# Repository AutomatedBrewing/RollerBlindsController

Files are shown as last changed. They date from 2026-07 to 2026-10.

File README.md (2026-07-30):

# Embedded build system
Sample implementation

## Setup

Before building, install all required dependencies:

```bash
./setup_repo.sh
```

For detailed information about dependencies, see [DEPENDENCIES.md](DEPENDENCIES.md).

## Building
To build specific target:
`./build.sh -c blink_F072`

## Formatting & Linting

The project uses `clang-format` and `clang-tidy` for code quality.

You can:
1. Format whole codebase: `./format_all.sh`
2. Run linting: `./lint_all.sh`
3. Check formatting on commit: `git-clang-format --diff --style=file HEAD`

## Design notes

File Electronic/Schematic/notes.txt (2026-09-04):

Simulate input
Add debug probes
Chose pin headers

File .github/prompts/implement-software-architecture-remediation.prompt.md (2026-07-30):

---
description: "Implements Project/Model/Architecture/software/REMEDIATION_PLAN.md phase by phase with maximum rigor: edits .sysml model files, self-verifies every change against SysML v2 rules and existing conventions, then runs a final adversarial re-review until zero Critical/Major findings remain. Read-write — the counterpart to review-software-architecture.prompt.md."
---

# Implement Software Architecture Remediation

Act as an extremely meticulous senior firmware/systems architect. This
prompt **modifies `.sysml` files**. Quality bar: every change must be
correct, minimal, consistent with existing model conventions, and never
based on invented facts. When a plan item is ambiguous or requires a
decision the model doesn't already support, **stop and ask the user**
instead of guessing.

## Step 0 — Load context (mandatory, in order)

1. `Project/Model/Architecture/software/REVIEW_FINDINGS.md` and
   `REMEDIATION_PLAN.md` — the exact scope of this work.
2. `.github/instructions/sysml-modeling.instructions.md` — binding rules for
   every edit (imports, requirement pattern, decomposition levels, proxy
   ports, `perform action`, anti-patterns).
3. Every file already under `Architecture/software/` (all subfolders) plus
   `Architecture/product/ProductComponents.sysml`, `ProductInterfaces.sysml`,
   `Architecture/states/SystemStates.sysml`, `Architecture/base/ADR_Common.sysml`,
   `Traceability/Traceability.sysml`.
4. `KnowledgeSource/swarch/crossmapping/building-block-view.md`,
   `cross-cutting-concepts.md`, `architecture-decisions.md` — the modeling
   patterns each new element must follow.
5. `KnowledgeSource/integration/okf-ontology.md §6.3` — required import
   matrix.

## Step 1 — Execute phases in order

Follow `REMEDIATION_PLAN.md` exactly, phase by phase (Phase 4 may run
concurrently with 1–3 since it has no dependency on them; do not reorder
otherwise — later phases depend on earlier decisions):

- **Phase 1** — ADR-SW-011 software layering decision.
- **Phase 2** — Event catalog + `EventDispatcher` element.
- **Phase 3** — Driver layer + inventory (5 new drivers, 3 new `*Internal`
  whitebox specializations, `PLAN.md` scoping update).
- **Phase 4** — Hierarchical state machine fixes (composite `Operational`
  super-state, dedupe `PowerLost` transitions, resolve `MovingManual` gap,
  dual-host summary table).
- **Phase 5** — Traceability wiring (import every `SWA-0x` package into
  `Traceability.sysml`, add `refines`/`depends_on` connections).
- **Phase 6** — Documentation conciseness (split the ~100-line
  `SWSolutionStrategy` doc block, trim `SWBuildingBlocks` header).
- **Phase 7** — Housekeeping (`Project/Model/README.md` folder-tree entry,
  naming-convention decision).

## Step 2 — Non-negotiable quality rules for every edit

- Every new/edited `.sysml` file has explicit `import` statements per the
  matrix in `okf-ontology.md §6.3` — no unresolved-type errors.
- New whitebox modules are added via specialization (`part def X_Internal :>
  ExistingPartDef`) — never by re-declaring an existing definition's name
  (SysML v2 has no reopening mechanism).
- Drivers stay **signature-free**: name, responsibility, owning module,
  layer placement only. No method/API design — that is explicitly SDD scope
  and must stay out.
- No invented technical facts. Every timing figure, attribute value, or
  responsibility statement must already exist in the model or be a direct,
  citable consequence of an existing ADR/constraint. If a genuinely new
  fact is unavoidable (e.g., a driver's resource estimate), mark it as an
  explicit placeholder attribute with a `// TODO` doc note rather than
  fabricating a precise number.
- `doc` blocks are short and information-dense: state the fact, cite the
  ADR/requirement/finding ID that justifies it, stop. No multi-topic essay
  blocks (this was Finding SWR-026 — do not reintroduce it anywhere).
- Every finding ID resolved by an edit gets a one-line comment reference
  (e.g., `// resolves SWR-006`) at the point of the fix, so the connection
  between finding and fix is visible in the diff.
- Proxy ports only, `part def` for structural elements (never SysML v1
  `actor`/`block`), two-layer requirement pattern where requirements are
  touched.
- Preserve every existing element's name, port, and attribute unless the
  plan item explicitly calls for a change — additive, non-invasive edits
  only.

## Step 3 — Self-verification after each phase

Before moving to the next phase, re-read your own edits adversarially
against this checklist (same categories as the review prompt, scoped to
what you just changed):

- **Compiles conceptually**: every referenced type/port/action exists;
  no dangling reference.
- **Layering**: no Application-level module reaches past its driver into
  raw hardware ports.
- **Drivers**: each new driver has exactly one owning module, one clear
  responsibility, no overlap with another driver.
- **Events**: every event in the catalog has a producer and at least one
  consumer; no orphan or unproduced event.
- **State machine**: every state has ≥1 outgoing transition or is
  explicitly terminal; every transition has a named trigger (or is a
  documented completion transition); guards sharing a trigger stay
  mutually exclusive; no duplicated transition logic across sibling states
  after Phase 4.
- **Traceability**: every new package is imported somewhere it should be
  reachable from `Traceability.sysml` by Phase 5's end.
- **Conciseness**: no `doc` block you wrote exceeds ~5 lines of substantive
  text.

Fix anything that fails before proceeding.

## Step 4 — Final acceptance pass (mandatory, after Phase 7)

Re-run the full adversarial review from `review-software-architecture.prompt.md`
Steps 2 (categories A–G) across the entire `Architecture/software/` folder
plus `SystemStates.sysml` and `Traceability.sysml`, as if you had not just
made the changes yourself. For every one of the 28 original findings
(`SWR-001`…`SWR-028`):
- Confirm it is now closed, and how.
- Or, if intentionally deferred (e.g., SWR-027's retroactive ADR-001–010
  tightening), state that explicitly with a reason — never silently drop it.

Update `Project/Model/Architecture/software/REVIEW_FINDINGS.md` in place:
add a `Status` column (`Closed` / `Deferred` + reason) to the existing
table, and update the Summary counts.

Update `REMEDIATION_PLAN.md`'s final line to reflect the new state:
`<N> Critical / <N> Major / <N> Minor open — READY for SDD handoff` (only
write `READY` once zero Critical/Major remain), or list what's still open
and why.

If the re-review surfaces any **new** finding introduced by your own edits,
add it to the findings table with a fresh `SWR-0NN` ID, fix it immediately
(this phase is read-write), and re-verify.

## Step 5 — Summary to user

End with a short report: phases completed, files created/edited (list),
findings closed vs. deferred (counts), and the final verdict line from
Step 4. No long narrative — bullet points only.

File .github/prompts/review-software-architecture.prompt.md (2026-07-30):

---
description: "Pedantic, exhaustive review of the firmware software architecture (layering, drivers/HAL, event catalog & signal flow, hierarchical state machine) under Project/Model/Architecture/software. Logs every finding, then produces a prioritized remediation plan. Read-only — never edits any .sysml file."
---

# Review Software Architecture (Pedantic)

Act as an extremely pedantic senior firmware/systems architecture reviewer.
**Read-only review** — do not modify any `.sysml` file. The only files you
write are the two reports in Step 3 and Step 4.

## Why this review exists

The current software architecture model
(`Project/Model/Architecture/software/`) stops short on four points:
1. No explicit software **layering** (Application/Service vs. Driver/HAL vs.
   hardware).
2. No explicit inventory of low-level **drivers** that must be written
   (HAL only — driver API/method signatures are SDD-level, out of scope here).
3. No single, readable **event catalog** and signal flow — events are only
   mentioned in ADR prose, never enumerated as first-class elements.
4. No confirmed-complete **hierarchical state machine** — states/transitions
   must all be explicit, unambiguous, and traceable.

Every finding and every remediation item must be short and concrete —
engineers reading this have no time for long paragraphs.

## Step 1 — Load context (read only)

Read, in order:
1. `Project/Model/README.md`, `Architecture/software/PLAN.md`.
2. `Architecture/base/BaseArchitecture.sysml`, `ADR_001`…`ADR_008`, `Constraints.sysml`, `SystemArchitecture_Taxonomy.sysml`.
3. `Architecture/product/ProductComponents.sysml`, `ProductInterfaces.sysml`, `LogicalToProductAllocation.sysml`.
4. `Architecture/states/SystemStates.sysml`.
5. Everything under `Architecture/software/`: `architecture_decisions/ADR_009_*`, `ADR_010_*`; `architecture_constraints/SWConstraints.sysml`; `building_block_view/SWBuildingBlocks.sysml`; `runtime_view/SWRuntimeScenarios.sysml`; `deployment_view/SWResourceBudget.sysml`; `cross_cutting_concepts/SWCrossCuttingConcepts.sysml`; `solution_strategy/SWSolutionStrategy.sysml`.
6. `KnowledgeSource/integration/crossmapping/physical-architecture.md`, `logical-architecture.md`, `product-architecture.md`, `system-states.md`.
7. `.github/instructions/sysml-modeling.instructions.md`.

## Step 2 — Review checklist (log EVERY finding — do not silently skip)

For each finding record: `ID` (`SWR-NNN`), `Severity`, `Area`,
`File:Element`, one-line `Finding`, one-line `Impact`.

**Severity**: `Critical` = blocks SDD handoff / structurally wrong or
missing; `Major` = real gap that must close before implementation starts;
`Minor` = wording/consistency/style nit.

### A. Software Layering
- Is there an explicit layered architecture (Application/Service ↔
  Driver/HAL ↔ hardware) modeled as packages/`part def`s with a documented
  boundary? (Expect: not yet — flag.)
- Does any firmware module (`CommandArbitrationSoftware`,
  `MovementControlSoftware`, `MotorDriveControlSoftware`,
  `MovementSupervisorSoftware`, `ConfigurationManagerSoftware`,
  `MemoryManagerSoftware`, `UserFeedbackSoftware`) reference hardware
  directly instead of through a driver abstraction? Flag every skipped
  layer.

### B. Driver Inventory (HAL only — NOT the API/SDD layer)
- Cross-reference every hardware peripheral implied by `ControlMCU` /
  `ProductInterfaces` / the ADRs: 4× debounced dry-contact GPIO inputs,
  motor output (relay/triac, up/down), timer peripheral (10 ms tick),
  internal EEPROM, buzzer output (ADR-008), any others found.
- For each peripheral, check whether a named driver building block exists
  anywhere in the model. Flag every missing one by the name it should have
  (e.g. `GpioInputDriver`, `MotorOutputDriver`, `TimerDriver`,
  `EepromDriver`, `BuzzerDriver`).
- State explicitly in the finding: only existence/responsibility/layer
  placement is in scope — method signatures belong to the SDD.

### C. Block Structure / Building Block View
- Is there one coherent block structure spanning Product → Software →
  Driver/HAL → Hardware, every connector traceable, no orphan modules, no
  layer-skipping connections?
- Is every module's responsibility non-overlapping with a single clear
  owner?

### D. Event Catalog & Signal Flow
- Extract every event referenced anywhere (debounced input-changed events,
  periodic timer tick, EEPROM access completion, buzzer trigger,
  state-machine triggers).
- Is there one authoritative, enumerated event catalog (name, producer,
  payload, consumer(s), trigger condition)? (Expect: not yet — flag.)
- For each event, trace producer → dispatcher → consumer → state-machine
  trigger (if any); flag inconsistent naming, events only in prose and
  never modeled, and events modeled but never produced/consumed.

### E. Hierarchical State Machine Completeness
- List every state and sub-state in `SystemStates.sysml` with its
  entry/do/exit.
- Verify every transition has an explicit trigger event + guard + effect;
  guards mutually exclusive; no orphan/unreachable state; no transition
  referencing an undefined event.
- Verify the state-machine host (`exhibit state` in
  `SWBuildingBlocks.sysml`) is consistent with `SystemStates.sysml` and
  that no other module partially re-implements state logic (cross-check
  Cross-cutting Concept 3).

### F. Traceability & SysML v2 Compliance
- Explicit imports present; no SysML v1 constructs; requirement
  def/usage pattern respected; proxy ports only; every ID traced in
  `Traceability/Traceability.sysml`.

### G. Documentation Conciseness
- Flag every `doc` block that is verbose/repetitive rather than short and
  information-dense. Note file/element only — the rewrite belongs in the
  remediation plan, not here.

## Step 3 — Findings Log

Write `Project/Model/Architecture/software/REVIEW_FINDINGS.md`:
- Summary counts (Critical/Major/Minor) at the top.
- One table, columns: `ID | Severity | Area | File:Element | Finding | Impact`.
- One row per finding — no prose paragraphs.
- Sorted by Severity, then Area.

## Step 4 — Remediation Plan

Write `Project/Model/Architecture/software/REMEDIATION_PLAN.md`:
- Numbered, ordered action items (group into phases only where a real
  dependency exists).
- Each item ≤ 3 lines: **What** to add/change, **Where** (exact file/package
  to create or edit), **Resolves** (finding IDs).
- Must include at least one item for each of: (1) layered architecture
  packages, (2) every missing driver named in Step 2B, (3) the single event
  catalog element wired into existing ADRs/cross-cutting concepts, (4) every
  HSM completeness gap, (5) rewriting every flagged verbose `doc` block.
- Bullet points and imperative mood only — no paragraphs.
- End with one line: `<N> Critical / <N> Major / <N> Minor open — NOT READY
  for SDD handoff until Critical+Major close` (or `READY` if none remain).

## Style rules (apply everywhere in both reports)

- Short, information-dense sentences. No filler, no repeated context.
- Bullets/tables over prose, always.
- Every finding and every action item must stand alone — understandable
  without reading the rest of the file.

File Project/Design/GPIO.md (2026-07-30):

| No. | PIN | Direction | Signal |
| --- | --- | --- | --- |
| 1 | ? | IN | Local UP |
| 2 | ? | IN | Local DOWN  |
| 3 | ? | IN | Remote UP |
| 4 | ? | IN | Remote DOWN |
| 5 | ? | OUT | Relay  UP |
| 6 | ? | OUT | Relay  DOWN |
| 7 | ? | OUT | Buzzer |
| 8 | ? | IN | VCC |
| 9 | ? | IN | GND |

Functional signals: 7

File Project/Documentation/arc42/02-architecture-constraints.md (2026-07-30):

# 2. Architecture Constraints

> Rendered from `Project/Model/Architecture/base/Constraints.sysml` (`L0_Constraints`),
> `Project/Model/Architecture/base/ADR_001_CostConstraint.sysml`, and
> `Project/Model/Architecture/base/ADR_003_TimeBased.sysml`.

| Constraint ID | Constraint | Background | Scope |
|---|---|---|---|
| `CNST-B-01` (`costEffective`) | Manufacturing cost ≤ 50 PLN per unit | Manufacturer `CostConcern`; drives ADR-001's "no MCU / relay-based / dry-contact" architecture (later revised by ADR-006) | Whole BOM (`ProductArchitecture::totalUnitCostPLN` asserts ≤ 50.0) |
| `CNST-P-01` (`compactDimensions`) | Dimensions ≤ 40×40×20 mm | User `MinimalSize` — must fit a typical ⌀60 flush-mounted junction box | Enclosure / physical form factor |
| `CNST-E-01` (`operatingConditions`) | Operate 0 °C – 40 °C | Manufacturer `OperatingConditions` — typical residential environment | Whole controller |
| `CNST-EL-01` (`supplyVoltage`) | 12 VDC ±10% (10–14 V) control supply | Fixed low-voltage logic supply rail | Control logic, interfaces |
| `CNST-EL-02` (`switchingLoad`) | Up to 8 A at 230 VAC motor switching | Represents standard residential roller-shutter motor load | MotorDriver / motor switching circuit |
| `CNST-EL-03` (`motorIsolation`) | Motor control circuitry galvanically isolated from low-voltage control logic | Safety — mitigates RISK-S-01 | MotorDriver ↔ ControlUnit boundary |
| `CNST-EL-04` (`inputIsolation`) | Galvanic isolation on all external input interfaces | Safety — mitigates RISK-S-01 | WallSwitchInterface, RemoteInterface |
| `CNST-A-01` (`noPositionFeedback`) | No position sensor/feedback from the shutter | Core architectural simplicity/cost decision (ADR-003); accepts residual RISK-T-01 | Movement supervision |
| `CNST-A-02` (`timeBasedOperation`) | Configurable time-based positioning only | Realizes `noPositionFeedback` without a sensor | Movement supervision, configuration |

## Category summary

| Category | Constraints |
|---|---|
| Business | `costEffective` |
| Physical | `compactDimensions` |
| Environmental | `operatingConditions` |
| Electrical | `supplyVoltage`, `switchingLoad`, `motorIsolation`, `inputIsolation` |
| Architectural | `noPositionFeedback`, `timeBasedOperation` |

## Architectural decisions driven by these constraints

- **ADR-001** (`ADR_001_CostConstraint`): cost target realized via no MCU
  (timer IC/discrete RC), relay-based switching, dry-contact I/O — partially
  superseded by **ADR-006** (MCU clause only; all other ADR-001 decisions
  remain in force).
- **ADR-003** (`ADR_003_TimeBased`): accepted trade-off realizing
  `noPositionFeedback`/`timeBasedOperation`, with RISK-T-01 (positioning
  drift) as a documented residual risk.

See [09-architecture-decisions.md](09-architecture-decisions.md) for the full
ADR set.

## Software Architecture Constraints (SWA-01)

> Rendered from `Project/Model/Architecture/software/architecture_constraints/SWConstraints.sysml`.
> Firmware-specific constraints derived from `ProductComponents::ControlMCU`'s
> attributes and from the base constraints above that also bind the software.

| Constraint | Category | Summary |
|---|---|---|
| `flashBudget` | Resource | Aggregate `estimatedFlashBytes` of the 7 firmware modules ≤ `flashSizeKB` with a 10% safety margin (preview check; authoritative check in [07-deployment-view.md §7.4](07-deployment-view.md)) |
| `ramBudget` | Resource | Aggregate `estimatedRamBytes` of the 7 firmware modules ≤ `internalRamBytes` with a 10% safety margin (same preview/authoritative split) |
| `memoryDiscipline` | Resource | No dynamic (heap) allocation; statically bounded call-stack depth, verified by static analysis (no runtime stack monitoring available on this MCU) |
| `noRtosAvailable` | Execution Model | `costEffective` already rules out an RTOS-capable MCU upgrade (ADR-001); execution model restricted to bare-metal designs (ADR-SW-009) |
| `dispatcherDeterminism` | Execution Model | The firmware event dispatcher must preserve `SystemStates::ControllerLifecycleState`'s already-verified determinism (mutually exclusive guards per triggering event) |
| `isrLatencyBudget` | Timing | Every ISR (timer tick + 4 GPIO change-notification interrupts) must complete within 10% of `timerResolutionMs` (1.0 ms), keeping ISR bodies to flag/timestamp updates only |
| `codingStandardConstraint` | Toolchain | Placeholder: a specific coding standard (e.g. MISRA-C subset) has not yet been selected; open item deferred to SWA-02/a dedicated ADR |

See [09-architecture-decisions.md](09-architecture-decisions.md) for
ADR-SW-009/ADR-SW-010, which these constraints bound.

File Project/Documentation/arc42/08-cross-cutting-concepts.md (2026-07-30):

# 8. Cross-cutting Concepts

> Rendered from `Project/Model/Analysis/domain/DomainKnowledge.sysml`,
> `Project/Model/Architecture/states/SystemStates.sysml`,
> `Project/Model/Architecture/base/ADR_003_TimeBased.sysml`,
> `Project/Model/Architecture/base/ADR_005_SecurityScope.sysml`.

## Concept 1 — Domain Vocabulary (Single Source of Truth)

`DomainKnowledge` (SM-PRD-15) defines every item/enum/flow type crossing a
function boundary — no downstream package redefines a term. Core types:
`MovementDirection` (`up`/`down`/`none`/`both`), `MovementMode` (`automatic`/
`manual`), `StopReason` (`timeout`/`userRequest`), `ChannelSource`,
`ConfigModeTransition`, `ControlCommand`, `MovementRequest`, `StopRequest`,
`MotorState`, `ShutterState`, `TravelTime`, `ConfigModeEvent`. See
[12-glossary.md](12-glossary.md) for full definitions.

## Concept 2 — Time-Based, Sensorless Positioning (ADR-003)

The single most pervasive cross-cutting concept: **no component anywhere in
the model reads shutter position.** Movement stop is always derived from
elapsed time against a persisted `TravelTime`, with a `+5s`/
`timingMarginS` margin (`MemoryManagerSoftware`) compensating for
cumulative drift (RISK-T-01, the architecture's explicitly accepted residual
risk). This discipline is enforced at every layer: `L0_Constraints::
Architectural::{noPositionFeedback,timeBasedOperation}`,
`UseCaseActivities::MonitorStopCondition`/`MonitorUserInterruption` (fork+
merge, first-of-{command,timeout} wins), through to
`LogicalMovementSupervisor`/`MovementSupervisorSoftware`.

## Concept 3 — First-Wins Arbitration & Conflict Suppression

Local and remote command channels are always received concurrently
(`ReceiveControlRequest`'s fork/merge) and arbitrated first-wins
(`CommandArbitrationSoftware.arbitrationWindowMs = 100 ms`). A simultaneous
opposite-direction (UP+DOWN) assertion is a **conflict**: `direction :=
none`/`both` is suppressed through `DetermineMovementRequest`→
`StartShutterMovement` so the motor is never energized in either direction
(REQ-S-01) — enforced with defense-in-depth at `MotorRelayOutputDriver`
itself. This same dual-channel-hold gesture, distinguished
only by duration (`calibrationHoldThresholdS = 5.0 s`,
`AssessingSimultaneousHold`), is also the trigger for entering
Configuration Mode — a single low-level signal pattern deliberately reused
for two distinct semantics.

## Concept 4 — Explicit, User-Signaled Configuration Mode

Configuration Mode (REQ-F-08) is entered/exited only through an explicit,
timed installer gesture, and every entry/exit is signaled to the user
(`ConfigModeEvent`, `DispatchConfigModeNotification`). Calibration
measurements outside the valid range (>120 s, REQ-F-07) are rejected rather
than persisted (`RejectOutOfRangeCalibration`) — a configuration-
input-validation pattern applied consistently at the UCA, Logical, and
Product layers.

## Concept 5 — State Model (Single Definition, Dual-Hosted)

`SystemStates.sysml` defines **one** state machine
(`ControllerLifecycleState`, full body on the `state def` itself, not
duplicated) exhibited by two different host `part def`s at two different
architecture layers (a previously-described second
`diagnosticLifecycle`/`DiagnosticState` machine on a `LogicalDiagnostics`
host does not exist in this model):

| Host `part def` | Layer | Usage name |
|---|---|---|
| `RollerShutterControllerWithLifecycle` | Logical | `rollerShutterControllerWithLifecycle` |
| `MovementSupervisorSoftwareInternal` | Product/Software | `movementSupervisorSoftwareInternal` |

`Uninstalled` → `Installing` → (`InstallationFault` | `Operational`,
entering at `Idle`) → `AssessingSimultaneousHold` →
(`ConflictSuppressed` | `ConfigurationMode`) → back to `Idle`;
`MovingAutomatic`/`MovingManual` from `Idle`; `Unpowered` (from any
`Operational` sub-state, or `Installing`) → `Operational` on recovery;
`Disposed` (terminal).

Cross-boundary event delivery for `PowerLost`/`PowerRestored` (producer:
`ProductComponents::PowerSupplyModule`, outside either host) is routed via
an explicit `CrossLifecycleEventRelay` part def, rather than
relying on SysML v2's ambiguous default "containing part" `accept` receiver.
`ConfigModeEvent` is within the host's own scope and does NOT route through
this relay; it has its own dedicated port/flow path instead.

## Concept 6 — No Dedicated Security Architecture (ADR-005, Scope Boundary)

Every external interface is dry-contact/relay based with no protocol stack,
no addressable identity, and no firmware-update channel — there is no
conventional attack surface. This is an explicit, falsifiable scope
decision (not a silent omission): it must be re-opened the moment any
networked/addressable interface, OTA update mechanism, data-at-rest/in-
transit capability, or remote diagnostic interface is introduced.

## Concept 7 — Firmware Resource Budgeting on a Shared MCU

Every firmware module hosted on `ControlMCU` carries an illustrative
`estimatedFlashBytes`/`estimatedRamBytes` pair, summed and checked
against `ControlMCU.flashSizeKB`/`internalRamBytes` — a lightweight,
model-level capacity-planning discipline applied uniformly across all 7
modules rather than to any single one.

## Software Cross-cutting Concepts (SWA-06)

> Rendered from `Project/Model/Architecture/software/cross_cutting_concepts/SWCrossCuttingConcepts.sysml`.
> Firmware-wide conventions distilled from recurring patterns observed while
> producing the Software Building Block View (SWA-03); each is backed by a
> concrete SWA-03 instance and traced to its originating SWA-01 constraint or
> ADR.

### Concept 8 — No Dynamic Memory Allocation

Origin: `SWConstraints::Resource::memoryDiscipline` (SWA-01). No firmware
module may use heap/dynamic allocation; every internal data item is
statically declared — e.g. `CommandArbitrationSoftwareInternal`'s
`lastLocalEdgeMs`/`lastRemoteEdgeMs`. Checkable via the
`NoDynamicAllocationMeta` marker applied to all 7 firmware `part def`s.

### Concept 9 — Single Shared Timing Source

Origin: ADR-003 / ADR-SW-009. No module may introduce its own independent
timing source; every elapsed-time measurement (movement timeout,
hold-to-run, ADR-SW-010's debounce bookkeeping) is derived from counting the
same `timerResolutionMs` (10 ms) tick — reflected in the four
`ConfirmInputDebounce` instances all sharing one tick source. Checkable via
the `SharedTimingSourceMeta` marker, applied to the two modules that
concretely consume the shared tick (`CommandArbitrationSoftware`,
`MovementSupervisorSoftware`).

### Concept 10 — Event-Dispatcher State-Machine Execution

Origin: ADR-SW-009. Every firmware module is a non-blocking event handler
invoked from the single superloop dispatcher, and the exhibited
`ControllerLifecycleState` machine is driven by the same dispatcher, never
its own scheduling mechanism — demonstrated end-to-end by
`SWRuntimeScenarios::RSCEN_02`/`RSCEN_03`. Checkable via the
`EventDispatcherExecutionMeta` marker, applied to all 7 firmware modules.

### Concept 11 — Single-Owner EEPROM Persistence Access

Origin: `ProductComponents::MemoryManagerSoftware` is the sole module with
ports touching `internalEepromBytes`; every other module reaches
`TravelTime` data only through its `durationOut`/`timingIn` flow
connections, avoiding concurrent/interleaved EEPROM writes on an MCU with no
OS-level locking. Checkable via the `SingleOwnerEepromMeta` marker, applied
to `MemoryManagerSoftware`, the sole owning module.

### Event Catalog & `EventDispatcher` (SWA-06 extension)

> Rendered from `Project/Model/Architecture/software/cross_cutting_concepts/SWEventCatalog.sysml`.
> The single enumerated catalog of every event crossing a module boundary,
> naming the two firmware-level events (`DebouncedInputChanged`,
> `TimerTick`) and the structural home for ADR-SW-009's "event dispatcher".

| Event | Producer | Consumer |
|---|---|---|
| `BeginInstallation` | Installer (external actor) | `Uninstalled` → `Installing` |
| `InstallationVerified` | `InstallController` | `Installing` → `Operational` |
| `InstallationFaultReported` | `InstallController` | `Installing` → `InstallationFault` |
| `DecommissionRequest` | User/Manufacturer (external actor) | `{Idle, Unpowered}` → `Disposed` |
| `PowerLost` | `PowerSupplyModule` | `{Operational, Installing}` → `Unpowered`, via `crossLifecycleEventRelay` |
| `PowerRestored` | `PowerSupplyModule` | `Unpowered` → `Operational`, via `crossLifecycleEventRelay` |
| `DebouncedInputChanged` | `CommandArbitrationSoftwareInternal`'s 4 `ConfirmInputDebounce` instances | `eventDispatcher.pendingIn`/`dispatchedOut` (proxy-port mediated) → `arbitrateChannels` (flow-realized) |
| `TimerTick` | `TimerDriver` | Production flow-realized to `eventDispatcher.pendingIn.timerTick`; state-machine consumption stays on `SystemStates`' native `accept after` (deliberate — no redundant dispatch route) |

`EventDispatcher` (`part def`, mirrors `SystemStates::CrossLifecycleEventRelay`'s
explicit event-routing pattern one layer down) is proxy-port mediated
(`pendingIn`/`dispatchedOut`) and holds at most one pending
instance of each routed event type (`pendingIn.debouncedChange`,
`pendingIn.timerTick` — both `[0..1]`, never queued/batched).

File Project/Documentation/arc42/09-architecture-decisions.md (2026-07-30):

# 9. Architecture Decisions

> Rendered from `Project/Model/Architecture/base/ADR_001..008_*.sysml`
> (`@ArchDecisionMeta`, `ADR_Common`). All 8 ADRs are `status = "accepted"`.

| ADR | Title | Status / Supersede Chain |
|---|---|---|
| ADR-001 | Cost target (<50 PLN BOM) via architectural simplicity: no MCU, relay switching, dry-contact I/O | Accepted; **partially superseded by ADR-006** (MCU clause only — relay switching, dry-contact I/O, form factor, and 50 PLN target remain in force) |
| ADR-002 | Availability realized by relay-hardware MTBF, not a behavioral sub-system | Accepted |
| ADR-003 | Time-based shutter positioning with no position sensor | Accepted |
| ADR-004 | Loose (allocation) Functional→Logical coupling; strong (`:>`) Logical→Base coupling where a 1:1 counterpart exists | Accepted |
| ADR-005 | No dedicated cybersecurity requirement/architecture | Accepted |
| ADR-006 | Single low-cost 8-bit MCU hosting eight modular firmware components | Accepted; **supersedes ADR-001**'s MCU clause; sub-decision (6) LED feedback **superseded by ADR-008** |
| ADR-007 | Strong coupling for clean 1:1 Logical→Product realizations; loose (allocation) wherever ADR-006 splits a Logical component across multiple Product components | Accepted |
| ADR-008 | Active buzzer replaces bi-color LED for user feedback | Accepted; **supersedes ADR-006 sub-decision (6)** only |

## ADR-001 — Cost Target via Architectural Simplicity

- **Context:** Manufacturer `costConcern` demands manufacturing cost ≤ 50 PLN
  (`costEffective`).
- **Decision:** No MCU (timer IC/discrete RC), relay-based motor switching,
  dry-contact-only I/O, compact single-PCB form factor.
- **Superseded (partial) by ADR-006:** cost/BOM math changed once sub-2-PLN
  8-bit MCUs became available; only the "no MCU" clause is revised.

## ADR-002 — Availability via Hardware MTBF

- **Context:** REQ-Q-02 (≥99.8% availability) has no natural behavioral
  chain — the controller has no OS, scheduler, or moving software parts;
  primary failure mode is relay wear-out (RISK-T-03).
- **Decision:** Satisfied passively via relay/component MTBF selection
  (expected ≤3650 cycles/year, well within the 10,000-cycle REQ-Q-03
  endurance target). No `availabilityFunctions` FE is introduced.
- **Consequences:** Intentional gap in the UC→UCA→FA behavioral chain for
  REQ-Q-02; Physical/Product Architecture review must verify component MTBF
  against the target; a future self-test FE would require a superseding ADR.
- **Alternatives considered:** (A) dedicated `selfTestFunctions` FE — deferred
  as premature/speculative; (B) product-level MTBF constraint — rejected,
  loses REQ-Q-02's time-window semantics.

## ADR-003 — Time-Based Positioning, No Position Sensor

- **Decision:** Movement stop derived purely from elapsed time against a
  configurable `TravelTime`; no position feedback of any kind.
- **Accepted residual risk:** RISK-T-01 (positioning drift), mitigated by a
  documented `+5s`/`timingMarginS` margin convention.

## ADR-004 — Functional↔Logical↔Base Coupling Strategy

- **Context:** SYSMOD mandates loose (allocation) Functional→Logical
  coupling; Logical→Base coupling is a project choice given 5 preset Base
  parts independent of the 8-FE functional decomposition.
- **Decision:** (1) Functional→Logical always loose (`allocation def
  FunctionToLogicalComponent`). (2) Strong (`:>`) Logical→Base for the 4
  components with an unambiguous 1:1 counterpart (`LogicalControlUnit`,
  `LogicalMotorDrive`, `LogicalLocalRequestInterface`,
  `LogicalRemoteRequestInterface`). (3) `PowerModule` has no Logical
  counterpart — reappears only from Product Architecture onward. (4)
  `LogicalMovementSupervisor` and `LogicalUserNotification` are plain
  `part def` (no Base precedent). (5) `requestAcquisitionFunctions` is the
  one documented 1-FE-to-2-component split.
- **Note (resolves SWR-037):** an earlier `LogicalDiagnostics` component was
  removed from the model permanently (`PLAN.md`); this rendering no longer
  lists it.

## ADR-005 — No Dedicated Security Scope

- **Context:** All 3 external interfaces (`WallSwitch`, `HomeAutomationSystem`,
  power) are dry-contact/relay/electrical — no protocol stack, no
  addressable identity, no attack surface in the conventional sense.
- **Decision:** No `SecurityReq` category, use case, or architecture element
  introduced. Absence of a data/network interface is treated as satisfied by
  the existing `L0_Constraints::Architectural` scope.
- **Explicit re-evaluation trigger:** any networked/addressable interface,
  OTA firmware update, data-at-rest/in-transit capability, or remote
  diagnostic interface introduced in the future.
- **Alternatives considered:** (A) speculative placeholder `SecurityReq`
  category — rejected as over-engineered; (B) silent omission — rejected,
  indistinguishable from an oversight.

## ADR-006 — Single MCU, Modular Firmware

- **Context:** Logical Architecture review's mandatory follow-up: split
  `LogicalControlUnit`'s 4-FE concentration into separately
  replaceable/testable units before finalizing the design. Discrete-timer
  realization (ADR-001's original proposal) cannot practically support
  configuration-mode calibration or fault classification.
- **Decision:** (1) One low-cost 8-bit MCU (`ControlMCU`, STM8S003F3P6-class)
  as the shared compute platform. (2) Concentration resolved via **software**
  modularization (7 firmware modules: `CommandArbitrationSoftware`,
  `MovementControlSoftware`, `MotorDriveControlSoftware`,
  `ConfigurationManagerSoftware`, `MemoryManagerSoftware`,
  `UserFeedbackSoftware`, `MovementSupervisorSoftware`)
  rather than hardware fragmentation. (3) `TravelTime` stored in internal
  EEPROM. (4) Motor switching remains relay-based (reaffirms ADR-001). (5)
  All external interfaces remain dry-contact/relay-only (reaffirms ADR-001,
  ADR-005). (6) User feedback via bi-color LED — **superseded by ADR-008**.
- **Note (resolves SWR-037):** an earlier eighth module, `DiagnosticsSoftware`,
  was removed from the model permanently (`PLAN.md`); this rendering lists
  the current 7 modules only.

## ADR-007 — Logical→Product Coupling Strategy

- **Decision:** Mirrors ADR-004's per-component pattern. Strong (`:>`) for
  1:1 realizations (`MovementSupervisorSoftware`,
  `PowerSupplyModule :> PowerModule`). Loose (allocation) wherever ADR-006's
  software split crosses a Logical component into multiple Product
  components (`LogicalControlUnit`, `LogicalMotorDrive`,
  `LogicalUserNotification`, and both request interfaces). `ControlMCU` is
  allocated FROM five Logical components without itself specializing any one
  (many-to-one hosting). `EnclosureAndConnectors` has no Logical/Base
  counterpart — traced directly to constraints/requirements instead.

## ADR-008 — Buzzer Replaces LED

- **Context:** ADR-006's bi-color LED is not observable once the controller
  is flush-mounted inside a junction box.
- **Decision:** Replace the LED with a single active buzzer
  (`AudibleNotificationBuzzer`, `BuzzerControlPort`), software-timed pulse
  patterns distinguishing configuration-mode activation and deactivation
  (REQ-F-08) — the buzzer's only two purposes.
- **Supersedes:** ADR-006 sub-decision (6) only; all other ADR-006 decisions
  unaffected.

## Software Architecture Decisions

> Rendered from `Project/Model/Architecture/software/architecture_decisions/ADR_009_SWExecutionModel.sysml`,
> `ADR_010_InputDebouncing.sysml`, and `ADR_011_SoftwareLayering.sysml`. All 3 `status = "accepted"`.

| ADR | Title | Status |
|---|---|---|
| ADR-SW-009 | Bare-metal, event-driven superloop execution model | Accepted |
| ADR-SW-010 | Per-line GPIO change-notification interrupts + software debounce confirmation | Accepted |
| ADR-SW-011 | Three-layer software architecture (Application / Driver-HAL / Hardware) | Accepted |

### ADR-SW-009 — Firmware Execution Model

- **Context:** `ControlMCU` is an 8-bit MCU (16 KB flash / 1 KB RAM / 16 MHz,
  ADR-006); ADR-001's cost ceiling already rules out an RTOS-capable
  upgrade. ADR-003 established timer-based movement supervision
  (`timerResolutionMs = 10 ms`). ADR-SW-010 separately establishes
  per-line GPIO debouncing; this ADR only decides HOW the firmware is
  scheduled given both event sources.
- **Decision:** The main loop is an event dispatcher reacting to (a)
  debounced input-changed events (ADR-SW-010) and (b) the periodic 10 ms
  timer tick. All seven firmware modules are non-blocking event
  handlers/functions invoked from the dispatcher, never blocking inside an
  ISR.
- **Alternatives considered:** (A) RTOS — rejected, no flash/RAM headroom
  and no genuine concurrency need. (B) Cooperative round-robin scheduler
  with per-module task control blocks — rejected, RAM overhead with no
  benefit. (C) Flat sequential polling loop — rejected, does not compose
  cleanly with porting the team's existing event-driven abstraction library
  to bare-metal.
- **Consequences:** ISR bodies stay minimal (flag/timestamp updates only);
  GPIO/timer resource accounting deferred to
  [07-deployment-view.md §7.4](07-deployment-view.md).
- **Open item:** whether the team's existing FreeRTOS-backed event-driven
  abstraction library is reused (vs. a from-scratch bare-metal dispatcher)
  is deferred pending review of its sources.

### ADR-SW-010 — Input Debouncing & GPIO Strategy

- **Context:** `RequestInterfaceCircuit`'s RC glitch filter
  (`debounceTimeConstantMs = 20 ms`) filters electrical noise only — not
  genuine mechanical wall-switch bounce. Reliable input handling requires
  the four underlying signal lines (local/remote up/down) to be
  individually observable.
- **Decision:** Each of the four input lines gets its own dedicated GPIO
  change-notification interrupt (`inputChangeNotificationGpioCount = 4`).
  Each interrupt only timestamps/flags the raw transition;
  `CommandArbitrationSoftware` confirms stability for `debounceConfirmMs`
  (30 ms) before raising a debounced event. `arbitrationWindowMs` widened
  from 50 ms to 100 ms as part of this decision, so the ~50 ms worst-case
  combined RC+software debounce latency stays well below the arbitration
  window.
- **Alternatives considered:** (A) Hardware RC debounce only, no software
  confirmation — rejected, misclassifies genuine mechanical bounce as
  separate commands. (B) Sampling all four lines each timer tick instead of
  per-line interrupts — rejected, loses precise per-line timestamping for
  no resource saving. (C) Sampling only the two combined dry-contact ports
  — rejected, loses the ability to individually debounce each physical
  line.
- **Consequences:** 4 of `ControlMCU`'s 14 GPIOs reserved for
  change-notification interrupts, leaving 10 for relay/buzzer/prog port and
  margin (see [07-deployment-view.md §7.4](07-deployment-view.md) for the
  full pin accounting).

### ADR-SW-011 — Software Layering

- **Context:** No layer boundary was ever recorded, so every firmware module
  was free to reach hardware directly; ADR-SW-009 (execution model) and
  ADR-SW-010 (debouncing) already assumed a driver/hardware split implicitly
  but never stated it.
- **Decision:** Three layers — Application (arbitration/translation/
  supervision/persistence logic) → Driver/HAL (`GpioInputDriver`,
  `TimerDriver`, `MotorRelayOutputDriver`, `BuzzerOutputDriver`,
  `EepromDriver`, nested `part def`s in `SWBuildingBlocks.sysml`) → Hardware
  (`ControlMCU` peripherals, `RequestInterfaceCircuit`,
  `MotorDriveRelayModule`, `AudibleNotificationBuzzer`, already in
  `ProductComponents.sysml`). No Application-level action may reference a
  hardware-facing port directly; it goes through its module's driver only.
- **Alternatives considered:** (A) No explicit layering (status quo) —
  rejected, the exact gap this ADR closes. (B) Runtime-polymorphic HAL
  abstraction — rejected, RAM/flash overhead unjustified on a
  fixed-peripheral 8-bit MCU (`SWConstraints::Resource::memoryDiscipline`
  forbids the dynamic dispatch tables such an abstraction needs).
- **Consequences:** every hardware-facing port on `CommandArbitrationSoftware`,
  `MovementSupervisorSoftware`, `MotorDriveControlSoftware`,
  `UserFeedbackSoftware`, `MemoryManagerSoftware` is reached via a nested
  driver.

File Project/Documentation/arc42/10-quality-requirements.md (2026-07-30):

# 10. Quality Requirements

> Rendered from `Project/Model/Analysis/requirements/Requirements.sysml`
> (packages `Quality`, `Safety`),
> `Project/Model/Verification/test_cases/SystemTestCases.sysml`.

## Quality Requirements Overview (Quality Tree)

| ID | Requirement | Stakeholder | Target | Verified by (`SystemTestCases`) |
|---|---|---|---|---|
| REQ-Q-01 | easeOfInstallation | Installer | ≤ 30 min first-time install | `TC_Q_001_InstallationTime` |
| REQ-Q-02 | availability | User | ≥ 99.8% valid-request success rate | `TC_Q_002_OperationalAvailability` |
| REQ-Q-03 | reliability | User | ≥ 10,000 operation cycles w/o failure | `TC_Q_003_ReliabilityEndurance` |
| REQ-S-01 | safety | User | SELV (≤50 V AC) exposed; galvanic isolation; conflict suppression | `TC_S_001`, `TC_S_002`, `TC_S_003` |

## Quality Scenarios

| ID | Stimulus | Environment | Response | Response Measure | Test case |
|---|---|---|---|---|---|
| QS-01 | First-time installer begins install | New installation site | Installer completes install + basic verification | ≤ 30 min (`TC_Q_001_InstallationTime`) | TC_Q_001 |
| QS-02 | N valid control requests issued over operational life | Normal field operation | Controller executes request | ≥ 99.8% success rate (`TC_Q_002_OperationalAvailability`) | TC_Q_002 |
| QS-03 | Repeated open/close cycling under rated load/temperature | Rated environmental conditions (`operatingConditions`) | Motor switching continues without functional failure | ≥ 10,000 cycles (`TC_Q_003_ReliabilityEndurance`) | TC_Q_003 |
| QS-04 (safety) | Simultaneous UP+DOWN assertion (same-source or cross-source) | Any operating state | Motor stays de-energized in both directions | 100% suppression (`TC_S_001`/`TC_S_002`) | TC_S_001, TC_S_002 |
| QS-05 (safety) | Any user/installer probes accessible interface points | Normal operation | No point exceeds SELV limit; isolation intact | ≤ 50 V AC, isolation verified (`TC_S_003_AccessibleVoltage_SELV`) | TC_S_003 |

## Test Case Register (`Project/Model/Verification/test_cases/SystemTestCases.sysml`)

37 `verification def`s, all carrying `@TestCaseMeta {testType,
verificationMethod, priority, category}`, organized into 6 packages:

| Category | IDs | Count | Requirements covered |
|---|---|---|---|
| Functional | TC_F_001–014 | 14 | REQ-F-01..09, REQ-I-01/02 |
| Safety | TC_S_001–006 | 6 | REQ-S-01, REQ-F-06, REQ-F-08 |
| Quality | TC_Q_001–003 | 3 | REQ-Q-01..03 |
| Environmental | TC_E_001 | 1 | REQ-E-01 |
| Boundary | TC_B_001–007 | 7 | REQ-F-01, REQ-F-07, REQ-Q-03, REQ-S-01, `L0_Constraints::Electrical::{supplyVoltage,switchingLoad}`, `Environmental::operatingConditions`, `Physical::compactDimensions` |
| Negative | TC_N_001–006 | 6 | REQ-F-05/06/07/08, REQ-Q-01, REQ-I-01, `Architectural::{noPositionFeedback,timeBasedOperation}` |

### Boundary test cases (`Boundary` package)

| ID | Boundary condition |
|---|---|
| TC_B_001/002 | Supply voltage lower/upper bound (10.0 V / 14.0 V DC, ±10% of 12 V, `Electrical::supplyVoltage`) |
| TC_B_003 | `TravelTime` at exactly the 120 s max configurable travel time (REQ-F-07) |
| TC_B_004/005 | Ambient temperature lower/upper bound (0 °C / 40 °C, `Environmental::operatingConditions`) |
| TC_B_006 | Maximum rated switching load (8 A @ 230 V AC, `Electrical::switchingLoad`) |
| TC_B_007 | Maximum enclosure envelope (40×40×20 mm, `Physical::compactDimensions`) |

### Negative test cases (`Negative` package)

| ID | Scenario |
|---|---|
| TC_N_001 | Manual-mode safety timeout fires even while command is still held (failsafe) |
| TC_N_002 | Re-activating configuration mode while already active — no double-notification/lockup |
| TC_N_003 | Installation wiring-verification retry path (corrects and re-verifies) |
| TC_N_004 | Confirms purely time-based operation, no position sensor dependency |
| TC_N_005 | Wiring-mode (momentary/latching) mismatch produces detectable incorrect behavior |
| TC_N_006 | Second consecutive verification failure → terminal installation fault |

### Component-scoped (white-box) verification defs (`SystemTestCases.sysml`)

| Package | Verification def | Subject (component) | Verifies |
|---|---|---|---|
| `Logical` | `VerifyCommandArbitration` | `LogicalControlUnit` | REQ-S-01, controlRollerShutter, stopShutterMovement, configurationMode |
| `Logical` | `VerifyConfigurationModeTransitions` | `LogicalControlUnit` | configurationMode |
| `Logical` | `VerifyUserNotificationDispatch` | `LogicalUserNotification` | configurationMode |
| `Logical` | `VerifyMotorDriveEndurance` | `LogicalMotorDrive` | reliability, availability |
| `Logical` | `VerifyMovementSupervisionTiming` | `LogicalMovementSupervisor` | fullShutterMovement, manualPositioning, stopShutterMovement, configurableTimingProfile |
| `Product` | `VerifyWiringModeConfiguration` | `CommandArbitrationSoftware` | wallSwitchWiringCompatibility, controlRollerShutter |
| `Product` | `VerifyMotorRelayEnduranceRating` | `MotorDriveRelayModule` | reliability, availability |
| `Product` | `VerifyRequestInterfaceIsolation` | `RequestInterfaceCircuit` | safety, `Electrical::inputIsolation` |

These 8 white-box verification defs are scoped to specific Logical/Product
components (`LogicalControlUnit`, `LogicalUserNotification`,
`LogicalMotorDrive`, `LogicalMovementSupervisor`,
`CommandArbitrationSoftware`, `MotorDriveRelayModule`,
`RequestInterfaceCircuit`) rather than only the black-box `ShutterController`
subject used throughout the `TC_*` register above — 5 in `Logical`, 3 in
`Product`.

## Notes

- All quality/safety requirements above have at least one `verification def`
  AND at least one concrete `SystemTestCases::TC_*` test case — no coverage
  gap exists for REQ-Q-01..03 or REQ-S-01.
- REQ-Q-02 (availability) is architecturally satisfied passively via
  hardware MTBF rather than a dedicated self-test function (ADR-002) — see
  [09-architecture-decisions.md](09-architecture-decisions.md).
- Full quality-attribute prioritization is in
  [01-introduction-and-goals.md](01-introduction-and-goals.md) (Quality
  Goals table).

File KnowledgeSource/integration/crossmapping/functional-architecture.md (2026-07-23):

---
okf_version: "0.1"
type: OKF Cross-Mapping
title: Cross-Mapping — Functional Architecture
description: Full SysML v2 and arc42 mapping for SYSMOD product Functional Architecture (SM-PRD-18).
timestamp: 2026-07-01T00:00:00Z
---

# Cross-Mapping — Functional Architecture (SM-PRD-18)

The Functional Architecture provides a technology-independent functional description of the system using functional elements (FEs) that transform typed input flows into typed output flows. It is derived from Use Case Activities (SM-PRD-14) using the FAS (Functional Architectures for Systems) method. Although not a mandatory SYSMOD core product, the Functional Architecture is a highly valuable intermediate artifact that bridges analysis and the Logical / Physical architecture design phases.

## §1 SysMod Definition

**Product ID:** SM-PRD-18
**SYSMOD §:** 5.18
**Process:** [Architecture](../../sysmod/processes/architecture-process.md) (SM-PRC-2)
**Creating Method:** [4.17 Model the Functional Architecture](../../sysmod/methods/model-functional-architecture.md) (SM-MTH-17)
**Responsible Role:** [System Architect](../../sysmod/roles/system-architect.md)

### Purpose
The Functional Architecture describes the system as a network of technology-independent functional elements, each with typed input and output ports through which domain objects flow. It serves two primary engineering purposes: (1) it provides a clean functional interface contract independent of technology choices, enabling parallel hardware and software design streams; (2) it is the primary source for functional allocation to logical and product components (SM-PRD-20, SM-PRD-21).

### Role in Process
In the Architecture process (SM-PRC-2), the Functional Architecture is produced after the Analysis products (SM-PRD-14, SM-PRD-15) are complete. The FAS method systematically transforms Use Case Activity sub-functions into Functional Elements. The resulting Functional Architecture then drives the Logical Architecture (SM-PRD-20) through formal allocation relationships.

### Inputs

| # | Artifact | ID | Description |
|---|---|----|---|
| 1 | Use Case Activities | SM-PRD-14 | Sub-functions become functional elements; object flows become typed port interfaces |
| 2 | Domain Knowledge | SM-PRD-15 | Flow definitions and item types used to type functional ports and connections |
| 3 | System Architecture (abstract) | SM-PRD-17 | Taxonomic supertype context; FunctionalArchitecture specializes it |
| 4 | Requirements | SM-PRD-10 | Non-functional requirements constrain functional interface and element design |

### Outputs / Dependent Artifacts

| # | Artifact | ID | How Used |
|---|---|----|---|
| 1 | Logical Architecture | SM-PRD-20 | Functional elements are allocated to logical components via `allocation` |
| 2 | Scenarios | SM-PRD-22 | Functional interaction sequences provide runtime scenario content |
| 3 | arc42 Solution Strategy | ARC-04 | Functional decomposition rationale described as the core architectural strategy |
| 4 | arc42 Building Block View | ARC-05 | Functional elements become Level 1 building blocks |

### Dependencies
- **Requires:** SM-PRD-14 (Use Case Activities) — FEs are derived from UCA sub-functions via FAS.
- **Requires:** SM-PRD-15 (Domain Knowledge) — port types derive from domain flow definitions.
- **Benefits from:** SM-PRD-10 (Requirements) — non-functional constraints qualify functional interface design.
- **Related tool:** [FAS — Functional Architectures for Systems](../../sysmod/tools/functional-architectures-for-systems.md)

---

## §2 SysML v2 Mapping

### Mapping Table

| SYSMOD Concept | SysML v2 Element | Node ID | Rationale |
|---|---|---|---|
| Functional Element (FE) | `part def` | [SML-DEF-PartDef](../../sysml2/concepts/part-definition.md) | Each FE is a structural element with typed interface ports |
| FE input / output port | `port def` | [SML-DEF-PortDef](../../sysml2/concepts/port-definition.md) | Typed interaction point; typed by a `flow def` or `item def` from SM-PRD-15 |
| Functional connection | `connection def` | [SML-DEF-ConnDef](../../sysml2/concepts/connection-definition.md) | Connects output port of one FE to input port of another FE |
| Typed flow channel | `flow def` | [SML-DEF-FlowDef](../../sysml2/concepts/flow.md) | Specifies the data type carried by a functional connection |
| FE behavior | `action def` | [SML-DEF-ActDef](../../sysml2/concepts/action-definition.md) | The internal behavior performed by a functional element |
| Composite FA | `part def FunctionalArchitecture :> SystemArchitecture` | [SML-DEF-PartDef](../../sysml2/concepts/part-definition.md) | Top-level assembly containing all FE `part` usages and connections |
| FA structure diagram | Definition Diagram | [SML-DGM-DefDiag](../../sysml2/diagrams/definition-diagram.md) | Shows FE composition and typed port connections |
| FA behavior diagram | Action Flow Diagram | [SML-DGM-ActFlow](../../sysml2/diagrams/action-flow-diagram.md) | Shows data flow between FEs as an action activity |
| FA package | `package` | [SML-DEF-Package](../../sysml2/concepts/package.md) | Groups all FA definitions per system |

### Modeling Pattern

```sysml
package VehicleSystem_FunctionalArchitecture {

  // ── Import domain knowledge ───────────────────────────────────────────────
  import VehicleSystem_DomainKnowledge::*;
  import SystemArchitecture_Taxonomy::*;

  // ── Port definitions (typed by flow defs from Domain Knowledge) ──────────
  port def SpeedSensorPort     { in  item data : WheelSpeedData; }
  port def SpeedDataPort       { out item data : WheelSpeedData; }
  port def BrakingCommandPort  { in  item cmd  : BrakingCommand; }
  port def SafetyCommandPort   { out item cmd  : BrakingCommand; }
  port def ActuatorCommandPort { out item cmd  : BrakingCommand; }

  // ── Functional Elements ───────────────────────────────────────────────────
  part def FE_SensorProcessing {
    doc /* Collects raw sensor data and filters/normalizes it for downstream use */
    in  port sensorIn     : ~SpeedSensorPort;
    out port processedOut : SpeedDataPort;
  }

  part def FE_SafetyMonitoring {
    doc /* Monitors system health; enforces safety limits; overrides commands if needed */
    in  port dataIn    : ~SpeedDataPort;
    out port safetyCmd : SafetyCommandPort;
  }

  part def FE_BrakeControl {
    doc /* Translates braking decisions into actuator commands */
    in  port cmdIn       : ~BrakingCommandPort;
    out port actuatorOut : ActuatorCommandPort;
  }

  // ── Composite Functional Architecture ────────────────────────────────────
  part def FunctionalArchitecture :> SystemArchitecture {
    doc /* Top-level functional assembly of the Vehicle Control System (SM-PRD-18) */

    part sensorProc : FE_SensorProcessing;
    part safetyMon  : FE_SafetyMonitoring;
    part brakeCtrl  : FE_BrakeControl;

    connection c1 : SpeedDataFlow  connect sensorProc.processedOut to safetyMon.dataIn;
    connection c2 : BrakingFlow    connect safetyMon.safetyCmd     to brakeCtrl.cmdIn;
  }
}
```

### Recommended Package Structure

```
<System>_Architecture/
  functional/
    <System>_FunctionalArchitecture.sysml    ← part defs (FEs), port defs, connections
    <System>_FA_Diagrams.sysml               ← definition + action flow diagram views
```

---

## §3 arc42 Mapping

| arc42 Section | Node ID | Usage | Mandatory? |
|---|---|---|---|
| [Solution Strategy](../../arc42/sections/solution-strategy.md) | ARC-04 | Functional decomposition rationale: why these FEs were chosen, FAS method application, technology-independence principle | **MANDATORY** |
| [Building Block View](../../arc42/sections/building-block-view.md) | ARC-05 | Level 1 building blocks correspond to Functional Elements; ports and connections describe Level 1 interfaces | Optional |
| [Runtime View](../../arc42/sections/runtime-view.md) | ARC-06 | Functional FE interactions in specific scenarios (from SM-PRD-22) rendered as FE-level sequence diagrams | Optional |
| [Cross-cutting Concepts](../../arc42/sections/cross-cutting-concepts.md) | ARC-08 | Functional interface patterns (port stereotypes, flow typing conventions) documented as cross-cutting design rules | Optional |

**Placement guidance:** In ARC-04, document the FAS method application: list the UCAs used as input, describe how sub-functions were clustered into FEs, and state the rationale for the number and grouping of FEs chosen. In ARC-05, each `part def` FE becomes one Level 1 block diagram entry with its typed ports shown.

---

## §4 Traceability

### Incoming Links

| From Node | ID | Relationship | Description |
|---|----|---|---|
| Use Case Activities | SM-PRD-14 | `depends_on` | FEs are derived from UCA sub-functions via FAS transformation |
| Domain Knowledge | SM-PRD-15 | `depends_on` | Port types and flow definitions typed by domain entities |
| System Processes | SM-PRD-13 | `depends_on` | Process ordering informs FE collaboration sequences |
| System Architecture (abstract) | SM-PRD-17 | `depends_on` | FunctionalArchitecture specializes the abstract supertype |

### Outgoing Links

| To Node | ID | Relationship | Description |
|---|----|---|---|
| Logical Architecture | SM-PRD-20 | `implements` | Functional elements are allocated to logical components |
| Scenarios | SM-PRD-22 | `implements` | FE interactions become runtime scenario content |
| ARC-04 Solution Strategy | ARC-04 | `documents` | Functional decomposition rationale documented as core strategy |
| ARC-05 Building Block View | ARC-05 | `documents` | FEs become Level 1 building blocks with typed interfaces |

### Traceability Rules

1. Every `part def` Functional Element MUST trace to at least one UCA sub-function in SM-PRD-14.
2. Every `port def` MUST be typed by a `flow def` or `item def` from SM-PRD-15 (Domain Knowledge).
3. Every `connection` in the composite FA MUST be typed by a `flow def` or `connection def`.
4. The `FunctionalArchitecture part def` MUST carry `:> SystemArchitecture` from SM-PRD-17.
5. arc42 ARC-04 MUST identify the input UCAs and the clustering rationale for each FE.
6. Every FE MUST be allocated to at least one logical component in SM-PRD-20 via `allocation`.

---

## §5 Modeling Procedure

1. **Prepare the FAS input matrix** — list all UCA sub-functions from SM-PRD-14 in a table with columns: sub-function name, input item types, output item types, parent UCA source reference.
2. **Cluster sub-functions into Functional Elements** — apply FAS clustering rules: group sub-functions that share the same principal data type, implement the same physical transformation principle, or will naturally co-locate in the physical realization.
3. **Define `part def` FEs** — create one `part def` per functional element cluster; add a `doc` string describing the FE's single responsibility and its primary input-to-output transformation.
4. **Define port types** — for each FE boundary (interface), create a `port def` typed by the appropriate `flow def` from SM-PRD-15; use conjugate ports (`~PortDef`) for consuming ends to enforce directional consistency.
5. **Add `flow def` connection types** — ensure every inter-FE `connection` is typed by a `flow def`; derive flow types from SM-PRD-15 `item def` and `flow def` definitions.
6. **Assemble the composite `FunctionalArchitecture`** — create the top-level `part def` with `:> SystemArchitecture`; add `part` usages for each FE; add typed `connection` elements linking output ports to input ports.
7. **Generate diagrams** — create SML-DGM-DefDiag (structure showing parts and ports) and SML-DGM-ActFlow (data flow across FEs); review with stakeholders for completeness and correctness.
8. **Document in arc42** — write ARC-04 Solution Strategy citing the FAS method, the UCA sources, and the rationale for each FE cluster; create Level 1 building block descriptions in ARC-05 with typed interface descriptions.

---

### Relevant SYSMOD Tools

| Tool | ID | When to Apply |
|---|----|---|
| [Functional Architectures for Systems (FAS)](../../sysmod/tools/functional-architectures-for-systems.md) | Tool 11.2 | **Primary method** — use FAS clustering heuristics (step 2) to group UCA sub-functions into functional elements; provides a systematic, repeatable derivation technique |
| [Zigzag Pattern](../../sysmod/tools/zigzag-pattern.md) | Tool 11.6 | **Steps 1–3** — when clustering functional elements, recognize that technical grouping choices embed implicit architectural decisions; make these explicit as Base Architecture constraints (SM-PRD-07) or requirements (SM-PRD-10) |
| [Coupling of System Architectures](../../sysmod/tools/coupling-system-architectures.md) | Tool 11.7 | **After step 7** — decide before moving to SM-PRD-20 whether functional-to-logical coupling will be via `allocation def` (loose) or `part def :>` specialization (strong) |

---

*See also:* [OKF Ontology](../okf-ontology.md) · [System Architecture cross-mapping](system-architecture.md) (SM-PRD-17) · [Use Case Activities cross-mapping](use-case-activities.md) (SM-PRD-14) · [FAS tool](../../sysmod/tools/functional-architectures-for-systems.md)

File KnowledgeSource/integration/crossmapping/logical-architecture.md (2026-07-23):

---
okf_version: "0.1"
type: OKF Cross-Mapping
title: Cross-Mapping — Logical Architecture
description: Full SysML v2 and arc42 mapping for SYSMOD product Logical Architecture (SM-PRD-20).
timestamp: 2026-07-01T00:00:00Z
---

# Cross-Mapping — Logical Architecture (SM-PRD-20)

The Logical Architecture specifies the architectural and technical concepts of the system at a high abstraction level, using general technical elements (e.g., "Control Unit", "Communication Bus", "Sensor Interface") that are reusable across product families. It bridges the gap between the Functional Architecture (SM-PRD-18) and the concrete Product Architecture (SM-PRD-21) by introducing typed logical components and their interfaces without yet committing to specific hardware or software implementations. The Logical Architecture is a concrete child of the Physical Architecture (SM-PRD-19).

## §1 SysMod Definition

**Product ID:** SM-PRD-20  
**SYSMOD §:** 5.20  
**Process:** [Architecture](../../sysmod/processes/architecture-process.md) (SM-PRC-2)  
**Creating Method:** [4.18 Model the Logical Architecture](../../sysmod/methods/model-logical-architecture.md) (SM-MTH-18)  
**Responsible Role:** [System Architect](../../sysmod/roles/system-architect.md)

### Purpose

The Logical Architecture provides the first concrete physical architecture by decomposing the system into general technical concepts (logical components) with well-defined interfaces. It captures architectural decisions at a technology-independent level, enabling: (1) reuse of logical designs across product variants, (2) clean allocation of functional elements to structural elements, and (3) a stable architectural contract between the system architect and the subsystem designers. The Logical Architecture is the primary subject of architectural reviews before hardware and software selection is finalized.

### Role in Process

In the Architecture process (SM-PRC-2), Method 4.18 (Model the Logical Architecture) is executed after the Base Architecture (SM-PRD-07) has been established and the Functional Architecture (SM-PRD-18) is sufficiently stable. The System Architect: (1) identifies logical components by grouping related functional elements, (2) defines typed ports and interfaces, (3) establishes connections between components, (4) allocates functional elements to logical components, and (5) validates the architecture using Scenarios (SM-PRD-22). The Logical Architecture then serves as the generalization source for the Product Architecture (SM-PRD-21).

### Inputs (table)

| # | Input Artifact | ID | Description |
|---|---|---|---|
| 1 | Functional Architecture | SM-PRD-18 | Source of functional elements (`action def`) to be allocated to logical components |
| 2 | Base Architecture | SM-PRD-07 | Foundation; Logical System may specialize Base System via `part def LogicalX :> BaseX` |
| 3 | Requirements | SM-PRD-10 | Technical constraints determine component capabilities and interface specifications |
| 4 | System Context | SM-PRD-11 | External interface definitions at the system boundary |
| 5 | Domain Knowledge | SM-PRD-15 | Technology domain knowledge informs the choice of logical component types |

### Outputs / Dependent Artifacts (table)

| # | Dependent Artifact | ID | Relationship |
|---|---|---|---|
| 1 | Product Architecture | SM-PRD-21 | Concretizes the Logical Architecture; each logical component is specialized or allocated to a product component |
| 2 | Scenarios | SM-PRD-22 | Trace execution paths through logical architecture instances to verify correctness |
| 3 | Test Architecture | SM-PRD-24 | Uses the Logical Architecture as the specification of what is being tested |
| 4 | System States | SM-PRD-23 | States are exhibited on logical components; logical components appear as state-bearing parts |

### Dependencies

- **SM-PRD-18 (Functional Architecture):** Must be substantially complete before logical components can be identified through functional grouping. Each `action def` must map to exactly one logical component via `allocation def`.
- **SM-PRD-07 (Base Architecture):** Strong coupling uses `part def LogicalX :> BaseX`; loose coupling uses `allocation def`. The coupling strategy must be decided before modeling begins.
- **SM-PRD-10 (Requirements):** Interface specifications (port types, throughput, protocols) must be traceable to requirements. Requirement satisfaction is modelled with `satisfy`.

---

## §2 SysML v2 Mapping

### Mapping Table

| SYSMOD Element | SysML v2 Construct | Node ID | Rationale |
|---|---|---|---|
| Logical component | `part def` (specializing `PhysicalArchitecture`) | [SML-DEF-PartDef](../../sysml2/concepts/part-definition.md) | Each logical component is a typed, reusable structural element |
| Logical system assembly | `part def LogicalSystem :> BaseSystem` | [SML-DEF-PartDef](../../sysml2/concepts/part-definition.md) | Encapsulates the full set of logical components with their connections |
| Typed interface | `port def` | [SML-DEF-PortDef](../../sysml2/concepts/port-definition.md) | Captures the typed protocol or data-flow contract at a component boundary |
| Component connection | `connection def` | [SML-DEF-ConnDef](../../sysml2/concepts/connection-definition.md) | Formalizes the link between two port instances |
| Interface specification | `interface def` | [SML-DEF-IfaceDef](../../sysml2/concepts/interface-definition.md) | Groups related port definitions into a reusable interface contract |
| Functional allocation | `allocation def` | [SML-DEF-AllocDef](../../sysml2/concepts/allocation-definition.md) | Maps each `action def` from Functional Architecture to a logical component |
| Structural view | Definition Diagram | [SML-DGM-DefDiag](../../sysml2/diagrams/definition-diagram.md) | Shows component hierarchy, ports, and connections |
| Dynamic allocation view | Action Flow Diagram | [SML-DGM-ActFlow](../../sysml2/diagrams/action-flow-diagram.md) | Shows how functions flow through the logical component network |
| Requirement satisfaction | `satisfy` | [SML-USG-Satisfy](../../sysml2/concepts/satisfy.md) | Links logical components to their satisfying requirements |

### Modeling Pattern

```sysml
package VehicleSystem_LogicalArchitecture {

  // Strong coupling: Logical System specializes Base System (SM-PRD-07)
  part def LogicalVehicleControlSystem :> BaseSystem {
    part ecuControl   : LogicalECU;
    part sensorHub    : LogicalSensorInterface;
    part actuatorCtrl : LogicalActuatorInterface;
    part commBus      : LogicalCommunicationBus;

    connect ecuControl.sensorPort   to sensorHub.dataOutPort;
    connect ecuControl.actuatorPort to actuatorCtrl.cmdInPort;
    connect sensorHub.busPort       to commBus.nodePort;
    connect actuatorCtrl.busPort    to commBus.nodePort;
  }

  part def LogicalECU {
    doc /* General logical control unit — reusable across product families */
    port sensorPort   : ~SensorDataPort;
    port actuatorPort : ActuatorCmdPort;
    attribute processingCapacity : String;
    attribute safetyIntegrityLevel : String;
  }

  part def LogicalSensorInterface {
    port dataOutPort : SensorDataPort;
    port busPort     : BusNodePort;
    attribute sensorType : String;
  }

  part def LogicalActuatorInterface {
    port cmdInPort : ~ActuatorCmdPort;
    port busPort   : BusNodePort;
    attribute actuatorType : String;
  }

  part def LogicalCommunicationBus {
    port nodePort : BusNodePort[0..*];
    attribute protocol : String;
    attribute bandwidth : Real;
  }

  port def SensorDataPort   { attribute dataRate : Real; }
  port def ActuatorCmdPort  { attribute cmdRate : Real; }
  port def BusNodePort      { attribute busAddress : Integer; }

  // Functional allocation: SM-PRD-18 → SM-PRD-20
  allocation def FunctionToLogicalComponent {
    doc /* Each functional element from SM-PRD-18 is allocated to exactly one logical component */
    allocate FE_SensorProcessing  to LogicalSensorInterface;
    allocate FE_BrakeControl      to LogicalActuatorInterface;
    allocate FE_SafetyMonitoring  to LogicalECU;
    allocate FE_CommunicationMgmt to LogicalCommunicationBus;
  }
}
```

### Recommended Package Structure

```
<System>_Architecture/
  logical/
    <System>_LogicalArchitecture.sysml      ← Main logical architecture definition
    <System>_LogicalInterfaces.sysml        ← Port and interface definitions
    <System>_FunctionalAllocation.sysml     ← allocation def blocks (SM-PRD-18 → SM-PRD-20)
```

---

## §3 arc42 Mapping

| arc42 Section | ID | Relationship | Content Contributed |
|---|---|---|---|
| [Solution Strategy](../../arc42/sections/solution-strategy.md) | ARC-04 | **Mandatory** | Logical decomposition approach; coupling strategy (specialization vs. allocation); rationale for component grouping |
| [Building Block View](../../arc42/sections/building-block-view.md) (Level 2) | ARC-05 | **Mandatory** | Logical components and their interfaces; internal structure of the logical system; port connections between components |
| [Architecture Decisions](../../arc42/sections/architecture-decisions.md) | ARC-09 | **Mandatory** | Key decisions: which coupling strategy; how functional elements group into logical components; interface technology choices |
| [Runtime View](../../arc42/sections/runtime-view.md) | ARC-06 | Recommended | Dynamic behavior of logical components traced via Scenarios (SM-PRD-22) |
| [Cross-cutting Concepts](../../arc42/sections/cross-cutting-concepts.md) | ARC-08 | Recommended | Allocation pattern from functional to logical; reuse strategy for logical components |

---

## §4 Traceability

### Incoming Links (table)

| Source ID | Source Name | Link Type | Description |
|---|---|---|---|
| SM-PRD-19 | Physical Architecture [abstract] | `refines` | Logical Architecture is a concrete child of Physical Architecture |
| SM-PRD-07 | Base Architecture | `refines` | Logical System specializes (or is allocated from) Base System |
| SM-PRD-18 | Functional Architecture | `depends_on` | Functional elements are allocated to logical components |
| SM-PRD-10 | Requirements | `depends_on` | Requirements constrain logical component capabilities and interfaces |
| SM-PRD-11 | System Context | `depends_on` | External interfaces at the system boundary shape the outermost logical ports |

### Outgoing Links (table)

| Target ID | Target Name | Link Type | Description |
|---|---|---|---|
| SM-PRD-21 | Product Architecture | `refines` | Product components specialize or are allocated from logical components |
| SM-PRD-22 | Scenarios | `implements` | Scenarios instantiate logical components to verify architecture correctness |
| SM-PRD-24 | Test Architecture | `implements` | Test Architecture uses logical component definitions as the specification of the SUT |
| SM-PRD-23 | System States | `implements` | Logical components exhibit state machines defined in SM-PRD-23 |
| ARC-04 | Solution Strategy | `documents` | Logical decomposition strategy is documented in ARC-04 |
| ARC-05 | Building Block View | `documents` | Logical components appear as Level 2 building blocks in ARC-05 |

### Traceability Rules

1. Every `action def` in SM-PRD-18 (Functional Architecture) MUST appear in exactly one `allocation def` mapping it to a logical component.
2. Every logical `part def` MUST specialize `PhysicalArchitecture` (directly or transitively via `LogicalSystem`).
3. Every `port def` in the Logical Architecture MUST trace to at least one interface requirement in SM-PRD-10.
4. Every logical component that appears in a Scenario (SM-PRD-22) MUST be present as a `part` in `LogicalVehicleControlSystem` (or the system-specific equivalent).
5. Every logical component MUST appear in ARC-05 (Level 2) with a brief description and its key interfaces listed.

---

## §5 Modeling Procedure

1. **Review the Functional Architecture (SM-PRD-18).** Extract the complete list of `action def` elements, identifying functional clusters that are cohesive and loosely coupled. These clusters become the logical components. Aim for 5–10 top-level logical components for a system of typical complexity.

2. **Identify the coupling strategy with the Base Architecture (SM-PRD-07).** If the Base Architecture already defines component types that the Logical Architecture refines, use strong coupling: `part def LogicalX :> BaseX`. If the Logical Architecture is independent, use loose coupling via `allocation def`. Document this decision in ARC-09.

3. **Define logical component types (`part def`).** For each identified cluster, create a `part def` with: (a) typed `port` usages for each interface, (b) `attribute` declarations for key non-functional properties (e.g., `safetyIntegrityLevel`, `processingCapacity`). Avoid specific values — those belong in Product Architecture (SM-PRD-21).

4. **Define port and interface types (`port def`, `interface def`).** For each distinct interface protocol or data flow, create a `port def` with direction (conjugate `~` for receiving end) and relevant attributes (e.g., `dataRate`, `protocol`). Group related ports into `interface def` when reuse across multiple components is expected.

5. **Assemble the logical system structure.** Create `part def LogicalSystem :> BaseSystem` (or the project-specific name), add `part` usages for all logical components, and establish `connect` statements for all required interactions. Validate that every external interface from SM-PRD-11 is represented as a port on the boundary of `LogicalSystem`.

6. **Create functional allocation blocks.** Create one or more `allocation def` blocks mapping each `action def` from SM-PRD-18 to its logical host component. Ensure the allocation is complete — every functional element has exactly one allocation target.

7. **Validate with Scenarios (SM-PRD-22).** Before finalizing, trace at least three representative Use Case Activities (SM-PRD-14) through the Logical Architecture. Each trace should produce a sequence of part interactions; missing interactions or ports reveal gaps in the architecture.

8. **Populate arc42.** Write the logical decomposition rationale in ARC-04 (Solution Strategy), add each logical component as a Level 2 building block in ARC-05 with a one-paragraph description and interface table, and record key architectural decisions in ARC-09 (e.g., coupling strategy, protocol choices).

---

### Relevant SYSMOD Tools

| Tool | ID | When to Apply |
|---|----|---|
| [Coupling of System Architectures](../../sysmod/tools/coupling-system-architectures.md) | Tool 11.7 | **Before step 1** — decide whether to use strong coupling (`part def Logical :> Base`) or loose coupling (`allocation def`) between the Base Architecture and Logical Architecture; document the decision in ARC-09 |
| [Proxy versus Full Port](../../sysmod/tools/proxy-versus-full-port.md) | Tool 11.4 | **Step 4 (port definition)** — use proxy ports (`port def`) exclusively; bind proxy ports to internal structural parts via `connect`; avoids BOM ambiguity and keeps all structural parts as `part` usages |
| [Zigzag Pattern](../../sysmod/tools/zigzag-pattern.md) | Tool 11.6 | **Step 1 (component identification)** — recognize that deriving logical components from functional elements always surfaces new, lower-level requirements; capture these derived requirements in SM-PRD-10 and document the Base Architecture assumption behind them (ARC-02) |

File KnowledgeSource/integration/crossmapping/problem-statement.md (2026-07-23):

---
okf_version: "0.1"
type: OKF Cross-Mapping
title: Cross-Mapping — Problem Statement
description: Full SysML v2 and arc42 mapping for SYSMOD product Problem Statement (SM-PRD-04).
timestamp: 2026-07-01T00:00:00Z
---

# Cross-Mapping — Problem Statement (SM-PRD-04)

The Problem Statement is the first engineering artifact of the Analysis process and the root of the entire SYSMOD product dependency tree. It provides a structured, agreed description of the current situation (the problem), the desired situation (the goal), the gap between them, and the stakeholders affected. It is produced before any solution thinking begins. In SysML v2 it is modeled as a `requirement def` with structured documentation attributes, optionally strengthened by a `constraint def` for the formal gap expression. In arc42 it anchors the Requirements Overview subsection of ARC-01 and seeds the domain terminology in ARC-12.

## §1 SysMod Definition

**Product ID:** SM-PRD-04
**SYSMOD §:** 5.4
**Process:** [Analysis](../../sysmod/processes/analysis-process.md) (SM-PRC-1)
**Creating Method:** [4.5 Analyze the Problem](../../sysmod/methods/analyze-problem.md) (SM-MTH-05)
**Responsible Role:** [Project Manager](../../sysmod/roles/project-manager.md)

### Purpose

The Problem Statement forces the project to articulate the problem before proposing solutions. It documents: (1) the current state and its pain points, (2) the desired future state, (3) the gap that the new system must close, (4) the users and stakeholders affected, and (5) the impact of not solving the problem. An agreed Problem Statement prevents scope creep, aligns stakeholder expectations, and provides the logical foundation from which System Idea (SM-PRD-05) and System Objectives (SM-PRD-06) are derived.

### Role in Process

SM-PRD-04 is the first artifact in the Analysis process (SM-PRC-1). It has no SYSMOD product prerequisites and is created from stakeholder interviews, domain knowledge, and project initiation documents. All downstream analysis artifacts — System Idea, System Objectives, Stakeholders, Risks, Requirements — are traceable back to the Problem Statement. A change to the Problem Statement may invalidate or require revision of any of these downstream products.

### Inputs

| Input | Source | Description |
|---|---|---|
| Project Charter / Initiation Document | Project Manager | High-level statement of project motivation and business case |
| Stakeholder Interviews | Project Manager, System Engineers | Primary source of problem understanding from affected parties |
| Domain Expert Input | Domain Knowledge (SM-PRD-15) | Context about current processes, systems, and pain points |
| Market / Competitive Analysis | Product Owner / Marketing | External context on why the current situation is unsatisfactory |
| Regulatory / Mission Requirements | Compliance Officer | Obligations that define part of the "desired state" |

### Outputs / Dependent Artifacts

| Output / Dependent Artifact | ID | Relationship |
|---|----|---|
| System Idea | SM-PRD-05 | `refines` — The System Idea proposes a solution to the stated problem |
| System Objectives | SM-PRD-06 | `refines` — Objectives are measurable goals for closing the identified gap |
| Stakeholders | SM-PRD-08 | `refines` — The affected-users field seeds the stakeholder identification |
| Requirements | SM-PRD-10 | `refines` — Requirements must be traceable to the problem gap |

### Dependencies

SM-PRD-04 has **no upstream SYSMOD product dependencies**. It is the first artifact of the Analysis process and is created from external stakeholder inputs and project initiation documents.

---

## §2 SysML v2 Mapping

The Problem Statement is a stakeholder-facing artifact best modeled as a `requirement def` carrying structured documentary attributes. A `constraint def` can formalize the gap when a measurable or logical expression of the current-vs-desired state is possible.

### Mapping Table

| SYSMOD Element | SysML v2 Element | Element ID | Rationale |
|---|---|---|---|
| Problem Statement artifact | `requirement def ProblemStatement` | [SML-DEF-ReqDef](../../sysml2/concepts/requirement-definition.md) | Anchors the problem in the requirements hierarchy as a top-level stakeholder requirement before any system requirement is derived |
| Current situation description | `attribute currentState : String` | [SML-DEF-AttrDef](../../sysml2/concepts/attribute-definition.md) | Structures the narrative of the current state for machine-readable traceability |
| Desired situation description | `attribute desiredState : String` | [SML-DEF-AttrDef](../../sysml2/concepts/attribute-definition.md) | Structures the narrative of the target state |
| Gap description | `attribute problemGap : String` | [SML-DEF-AttrDef](../../sysml2/concepts/attribute-definition.md) | Makes the gap explicit and auditable |
| Affected users / stakeholders | `attribute affectedUsers : String[1..*]` | [SML-DEF-AttrDef](../../sysml2/concepts/attribute-definition.md) | Seeds the stakeholder list (SM-PRD-08) with the primary affected parties |
| Impact of non-resolution | `attribute impactIfNotSolved : String` | [SML-DEF-AttrDef](../../sysml2/concepts/attribute-definition.md) | Business-case attribute quantifying the cost or risk of inaction |
| Formal gap constraint | `constraint def ProblemGap` | [SML-DEF-ConstrDef](../../sysml2/concepts/constraint-definition.md) | Optional formal expression of the gap when the current and desired states can be quantified |
| Problem domain metadata | `metadata def ProblemContext` | [SML-DEF-MetaDef](../../sysml2/concepts/metadata-definition.md) | Annotates the Analysis package with domain, project phase, and approval status |

### Modeling Pattern

```sysml
package Analysis {

    requirement def ProblemStatement {
        doc /* Structured articulation of the problem before any solution is considered.
               Captures current state, desired state, gap, and affected stakeholders. */

        attribute currentState      : String;
        // Description of the existing situation and its pain points.

        attribute desiredState      : String;
        // Description of the future situation after the problem is solved.

        attribute problemGap        : String;
        // The specific gap between currentState and desiredState that the system must close.

        attribute affectedUsers     : String[1..*];
        // Primary stakeholders and user groups impacted by the current situation.

        attribute impactIfNotSolved : String;
        // Business, mission, or safety impact of leaving the problem unaddressed.

        attribute approvalStatus    : String = "draft";
        // "draft" | "under-review" | "approved" | "baselined"
    }

    // Example instantiation for a fictitious project
    requirement projectProblem : ProblemStatement {
        doc /* Engineers in the field cannot communicate equipment status
               to the control center in real time, causing unplanned downtime. */

        attribute currentState      = "Field engineers use paper-based logs; data reaches control center with 24-hour delay.";
        attribute desiredState      = "Real-time equipment status is visible to the control center; downtime is reduced by 30%.";
        attribute problemGap        = "No digital, real-time communication channel exists between field devices and the control center.";
        attribute affectedUsers     = ("Field Engineers", "Control Center Operators", "Maintenance Planners");
        attribute impactIfNotSolved = "Estimated €2M/year in unplanned downtime costs; safety risk from undetected equipment faults.";
    }

    constraint def ProblemGap {
        doc /* Formal constraint: the current mean time to detect a fault must exceed
               the desired detection time for the gap to remain open. */
        attribute currentDetectionTimeHrs  : Real;
        attribute desiredDetectionTimeHrs  : Real;
        constraint gapExists { currentDetectionTimeHrs > desiredDetectionTimeHrs }
    }

    metadata def ProblemContext {
        attribute projectName  : String;
        attribute domain       : String;   // e.g. "Industrial IoT", "Aerospace", "Automotive"
        attribute approvedBy   : String;
        attribute approvalDate : String;   // ISO 8601
    }
}
```

### Recommended Package Structure

```
<ProjectRoot>/
  Analysis/
    ProblemSpace/
      problem_statement.sysml    ← ProblemStatement requirement def + instance
      problem_constraints.sysml  ← ProblemGap constraint def (if formal gap exists)
      problem_context.sysml      ← ProblemContext metadata annotation
    StakeholderNeeds/             ← SM-PRD-05, SM-PRD-06, SM-PRD-08
    SystemContext/                ← SM-PRD-11
```

---

## §3 arc42 Mapping

| arc42 Section | ID | Mandatory / Recommended | What to Document |
|---|----|---|---|
| [Introduction and Goals](../../arc42/sections/introduction-and-goals.md) | ARC-01 | **Mandatory** | Requirements Overview subsection: summarize the problem statement narrative (current state, desired state, gap), the business motivation, and reference the full Problem Statement model artifact |
| [Glossary](../../arc42/sections/glossary.md) | ARC-12 | **Recommended** | Key domain terms introduced in the Problem Statement that are used consistently across all downstream artifacts (e.g., the names of the affected user groups, the domain-specific term for the "gap") |

**ARC-01 guidance:** The Requirements Overview in arc42 is the primary arc42 location for the Problem Statement. Include a prose summary of the three core fields (currentState, desiredState, problemGap) in 3–5 sentences. Add a link or reference to the full `ProblemStatement` requirement in the SysML v2 model. Avoid repeating the full model content — keep the arc42 section as a human-readable summary.

**ARC-12 guidance:** For every term that is defined in `affectedUsers` or that appears prominently in the `currentState` / `desiredState` descriptions, add a glossary entry with a one-line definition and domain context.

---

## §4 Traceability

### Incoming Links

| Source ID | Source Name | Link Type | Description |
|---|---|---|---|
| — | — | — | SM-PRD-04 has no upstream SYSMOD product predecessors |

### Outgoing Links

| Target ID | Target Name | Link Type | Description |
|---|---|---|---|
| SM-PRD-05 | System Idea | `refines` | The System Idea proposes a solution concept that directly addresses the stated problem gap |
| SM-PRD-06 | System Objectives | `refines` | Each objective is a measurable criterion for closing the gap identified in the Problem Statement |
| SM-PRD-08 | Stakeholders | `refines` | The `affectedUsers` attribute seeds the initial stakeholder identification |
| SM-PRD-10 | Requirements | `refines` | All requirements must be traceable to the problem gap; requirements that cannot be traced indicate gold-plating |

### Traceability Rules

1. **Problem-first rule:** No Analysis product (SM-PRD-05 through SM-PRD-16) may be baselined unless the Problem Statement is approved. Engineering work on requirements or architecture before an agreed Problem Statement is prohibited.
2. **Gap traceability rule:** Every system requirement (SM-PRD-10) must carry a `satisfy` or derivation link that traces back, directly or indirectly, to the problem gap described in SM-PRD-04.
3. **Change impact rule:** Any change to the `problemGap`, `currentState`, or `desiredState` attributes triggers a mandatory impact review on SM-PRD-05, SM-PRD-06, SM-PRD-08, and SM-PRD-10.
4. **Approved-before-architecture rule:** SM-PRD-04 must be approved (not merely drafted) before any Architecture process work (SM-PRD-17 onwards) begins.

---

## §5 Modeling Procedure

1. **Conduct stakeholder problem interviews.** Schedule structured interviews or workshops with representatives of each affected user group. Use a standard problem-analysis template covering: What is the current situation? What pain points does it cause? What would a better situation look like? What is the cost/risk of not fixing it?

2. **Draft the Problem Statement attributes.** From interview notes and project initiation documents, draft the five core attributes: `currentState`, `desiredState`, `problemGap`, `affectedUsers`, and `impactIfNotSolved`. Use precise, stakeholder-validated language for each.

3. **Create the SysML v2 Problem Statement model.** In the SME, create the `Analysis/ProblemSpace/` package. Define the `ProblemStatement requirement def` with all attributes. Create the project-specific requirement instance and populate all attribute values with the drafted content.

4. **Optionally formalize the gap as a constraint.** If the current-state and desired-state can be expressed in measurable terms (e.g., detection time, throughput, error rate), define a `ProblemGap constraint def` and link it to the Problem Statement requirement. This formal gap expression later becomes the acceptance criterion for the system.

5. **Annotate with ProblemContext metadata.** Apply the `#ProblemContext` annotation to the `ProblemSpace` package with the project name, domain, and approval status.

6. **Conduct a stakeholder review.** Present the drafted Problem Statement to all identified affected user groups and project sponsors for review and approval. Resolve conflicting views on the problem gap by facilitating a structured discussion. Update the model based on agreed feedback.

7. **Document in arc42.** Write the Requirements Overview subsection of ARC-01 as a prose summary of the Problem Statement, referencing the SysML v2 model. Add domain terms to ARC-12.

8. **Formally approve and baseline.** Obtain written approval of SM-PRD-04 from the Project Manager and key stakeholder representatives. Set `approvalStatus` to "baselined" in the model. This baseline is the formal prerequisite for starting SM-PRD-05 (System Idea) and SM-PRD-08 (Stakeholders).

---

### Relevant SYSMOD Tools

| Tool | ID | When to Apply |
|---|----|---|
| [6M Method](../../sysmod/tools/6m-method.md) | Tool 11.11 | **During step 1 (stakeholder interviews)** — run a 6M workshop to systematically explore causes across Manpower, Machinery, Materials, Methods, Measurement, and Mother-nature categories before drafting the problem gap |
| [Five Whys Method](../../sysmod/tools/five-whys-method.md) | Tool 11.12 | **During step 1** — use Five Whys root-cause analysis on each candidate problem to ensure the Problem Statement targets the root cause, not a symptom; document the why-chain in the model `doc` body |

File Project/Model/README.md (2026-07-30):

# Window Roller Shutter Controller model
This directory contains model for window roller shutter controller.

## Structure
Folder structure is organized based on SYSMOD process outputs (Analysis → Architecture →
Verification), following guidelines from the SYSMOD book (by Tim Weilkiens). One SysML v2
file per SYSMOD product. Since this repository models a single system, the `<System>_`
prefix recommended by SYSMOD for file/folder names is omitted for brevity — package names
inside each file remain fully qualified regardless of file path.

arc42 is treated as the *target publication format* rendered from this model — not a
parallel folder structure. arc42 sections are populated from `doc` blocks and metadata
annotations already present in the model elements below.

```
model/
  Analysis/                SYSMOD Analysis process outputs
    problem/                 Problem Statement, System Idea, System Objectives
    stakeholders/            Stakeholders and their concerns
    risks/                   Risks
    requirements/            System requirements
    context/                 System Context (external actors, interfaces)
    use_cases/                System Use Cases
    processes/                System Processes (use case ordering)
    use_case_activities/      Use Case Activities (functional decomposition)
    domain/                   Domain Knowledge (not yet modelled)
  Architecture/             SYSMOD Architecture process outputs
    base/                     Base Architecture + architectural constraints
    functional/               Functional Architecture
    logical/                   Logical Architecture
    product/                   Product Architecture
    software/                  Software Architecture (SWA-0x: firmware-internal decomposition)
      architecture_decisions/    ADR-SW-0xx firmware-specific Architecture Decision Records
      architecture_constraints/  SWA-01 resource/execution-model/timing constraints
      solution_strategy/         SWA-02 executive summary bridging Product -> firmware
      building_block_view/       SWA-03 whitebox decomposition + driver/HAL layer
      runtime_view/               SWA-04 firmware-execution-level scenarios
      deployment_view/            SWA-05 resource budget validation
      cross_cutting_concepts/     SWA-06 firmware-wide conventions + event catalog
    states/                    System States (SystemStates.sysml)
    scenarios/                 Scenarios
  Verification/             Verification-related outputs
    test_cases/                Test Cases / Verification
    test_architecture/         Test Architecture (not yet modelled)
  Traceability/             Cross-cutting derivation links between all products
```

See `KnowledgeSource/integration/okf-ontology.md §6` and
`KnowledgeSource/integration/crossmapping/<product>.md §2` for the full SYSMOD ↔ SysML v2
↔ arc42 mapping rationale behind this structure.

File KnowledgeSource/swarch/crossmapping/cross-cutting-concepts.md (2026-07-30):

---
okf_version: "0.1"
type: OKF Cross-Mapping
title: Cross-Mapping — Software Cross-cutting Concepts
description: Full SysML v2 and arc42 mapping for Software Architecture artifact Cross-cutting Concepts (SWA-06).
timestamp: 2026-07-01T00:00:00Z
---

# Cross-Mapping — Software Cross-cutting Concepts (SWA-06)

Software Cross-cutting Concepts document firmware-wide principles that apply
across multiple firmware building blocks (SWA-03) rather than belonging to
any single one — error handling, persistence conventions, timing/debounce
conventions, and state-binding naming — the software-discipline continuation
of arc42's Cross-cutting Concepts (ARC-08).

## §1 SysMod Definition

**Artifact ID:** SWA-06
**Not a SYSMOD product** — no direct SYSMOD precedent; System States (SM-PRD-23) already touches on system-wide behavioural conventions (its own crossmapping documents ARC-08 as a mandatory target), and SWA-06 is where the firmware-specific elaboration of that lives.
**Continues:** Recurring patterns observed while producing the Software Building Block View (SWA-03).
**Responsible Role:** Software Architect (project role).

### Purpose

To avoid inconsistent, ad-hoc solutions to the same recurring problem
scattered across firmware modules (e.g. every module inventing its own
debounce timing convention) by documenting the agreed convention once and
requiring all modules to follow it.

### Role in Process

Performed iteratively as SWA-03 (Building Block View) proceeds: whenever a
pattern recurs across two or more firmware components (e.g. how faults reach
an observable outcome such as a fault state or a signal attribute, how
EEPROM access is serialized), it is promoted from a per-component detail to
a documented cross-cutting concept here.

### Inputs (table)

| # | Input Artifact | ID | Description |
|---|---|---|---|
| 1 | Software Building Block View | SWA-03 | Recurring internal patterns are the source material for promotion to a cross-cutting concept |
| 2 | Software Architecture Constraints | SWA-01 | Resource constraints often *cause* a cross-cutting concept (e.g. "no dynamic allocation") |
| 3 | System States | SM-PRD-23 | State-machine naming/guard conventions that should be applied consistently across all `exhibit state` hosts |

### Outputs / Dependent Artifacts (table)

| # | Dependent Artifact | ID | Relationship |
|---|---|---|---|
| 1 | Software Building Block View | SWA-03 | Every firmware component's internal design must conform to the documented concepts |
| 2 | Software Architecture Decisions | SWA-07 | Cross-cutting concepts are often the direct consequence of a recorded decision |

### Dependencies

- **SWA-03:** A cross-cutting concept MUST be backed by at least one concrete instance already present in the Building Block View — this artifact documents recurring patterns, it does not invent speculative ones.

---

## §2 SysML v2 Mapping

### Mapping Table

| SW Architecture Element | SysML v2 Construct | Node ID | Rationale |
|---|---|---|---|
| Cross-cutting concept narrative | `doc` on a dedicated package | [SML-DEF-Package](../../sysml2/concepts/package.md) | Narrative explanation, consistent with how other cross-cutting narratives are captured in this project |
| Checkable convention marker | `metadata def <ConceptName>Meta { ... }` applied to conforming `part def`s | [SML-DEF-MetaDef](../../sysml2/concepts/metadata-definition.md) | Makes a convention traceable/queryable (e.g. which modules were checked for "no dynamic allocation") rather than purely narrative |

### Modeling Pattern

```sysml
package SWA_CrossCuttingConcepts {
    private import ProductComponents::*;

    metadata def NoDynamicAllocationMeta {
        attribute verified : Boolean;
    }

    doc
    /* Concept: No Dynamic Memory Allocation.
     * Given the 1KB RAM budget (SWA-01::ramBudget), no firmware module may
     * use dynamic (heap) allocation; all buffers are fixed-size and
     * statically allocated. */

    // Applied to each firmware part def already defined in ProductComponents.
    @NoDynamicAllocationMeta { verified = true; } // applied per part def, illustrative
}
```

### Recommended Package Structure

```
<System>_Architecture/
  software/
    cross_cutting_concepts/
      <System>_SWCrossCuttingConcepts.sysml   ← doc narratives + metadata def markers
```

---

## §3 arc42 Mapping

| arc42 Section | ID | Relationship | Content Contributed |
|---|---|---|---|
| [Cross-cutting Concepts](../../arc42/sections/cross-cutting-concepts.md) | ARC-08 | **Mandatory** | Firmware-wide conventions: error handling, persistence, timing/debounce, state-binding naming |
| [Architecture Decisions](../../arc42/sections/architecture-decisions.md) | ARC-09 | Recommended | Cross-reference to the decisions that originated each concept |

---

## §4 Traceability

### Incoming Links (table)

| Source ID | Source Name | Link Type | Description |
|---|---|---|---|
| SWA-03 | Software Building Block View | `depends_on` | Recurring internal patterns motivate each documented concept |
| SWA-01 | Software Architecture Constraints | `depends_on` | Resource constraints often cause a cross-cutting concept |
| SM-PRD-23 | System States | `depends_on` | State-machine conventions apply across every `exhibit state` host |

### Outgoing Links (table)

| Target ID | Target Name | Link Type | Description |
|---|---|---|---|
| SWA-03 | Software Building Block View | `enables` | Every firmware component's design must conform to the documented concepts |
| SWA-07 | Software Architecture Decisions | `implements` | Concepts trace back to the decision(s) that caused them |
| ARC-08 | Cross-cutting Concepts | `documents` | Rendered as the firmware-wide concept catalogue |

### Traceability Rules

1. Every documented concept MUST cite at least one concrete SWA-03 instance where it already applies.
2. Every concept that constrains firmware design (e.g. "no dynamic allocation") SHOULD have a corresponding checkable `metadata def` marker, not just prose.
3. Every concept SHOULD trace back to the SWA-07 decision (or SWA-01 constraint) that caused it.

---

## §5 Modeling Procedure

1. **Scan for recurring patterns.** While or after producing SWA-03, note any pattern (timing convention, error-propagation approach, persistence access style, state-binding naming) that appears in two or more firmware components.

2. **Promote each pattern to a named concept.** Write a `doc` narrative explaining the concept's intent, scope, and rationale.

3. **Add a checkable marker where useful.** For constraint-driven concepts (e.g. no dynamic allocation), define a `metadata def` and apply it to conforming `part def`s so conformance is queryable, not just asserted in prose.

4. **Cross-reference the originating decision.** Link each concept back to the SWA-07 ADR or SWA-01 constraint that caused it.

5. **Document in arc42.** Add each concept as a numbered Concept slot under ARC-08, following the arc42 template's own numbered-concept-slot convention.

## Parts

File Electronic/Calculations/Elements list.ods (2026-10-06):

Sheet: BOM
Element | Required elements | Picked element |  | Has datasheet | Missing model
UI indication | Buzzer | LD-BZEL-T56-0505 | LINK (https://www.tme.eu/pl/details/ld-bzel-t56-0505/sygnalizatory-elektromag-bez-generatora/loudity/) | YES
 | N-MOS | BSS138PW,115 | LINK (https://www.tme.eu/pl/details/bss138pw.115/tranzystory-z-kanalem-n-smd/nexperia/bss138pw-115/) | YES | YES
Input | Optoisolator 4x | LTV-247 | LINK (https://www.tme.eu/pl/details/ltv-247/transoptory-wyjscie-analogowe/liteon/) | YES
 | RC circuit
 | TVS | STS321150U751 | LINK (https://www.tme.eu/pl/details/sts321150u751-ea/diody-tvs-smd-jednokierunkowe/eaton-electronics/sts321150u751/) | YES
Output | Relay | AZ921-1A-12DE | LINK (https://www.tme.eu/pl/details/az921-1a-12de/przekazniki-elektromagn-miniaturowe/zettler/) | YES
 | N-MOS | BSS138PW,115 | LINK (https://www.tme.eu/pl/details/bss138pw.115/tranzystory-z-kanalem-n-smd/nexperia/bss138pw-115/) | YES
 | Reverse diode | 1N4148WSTR | LINK (https://www.tme.eu/pl/details/1n4148wstr-smc/diody-uniwersalne-smd/smc-diode-solutions/1n4148wstr/) | YES
Power supply | LDO | LDK320M33R | LINK (https://www.tme.eu/pl/details/ldk320m33r/stabilizatory-napiecia-nieregulowane-ldo/stmicroelectronics/) | YES
 | Reverse polarity | SDB160WS-AQ | LINK (https://www.tme.eu/pl/details/sdb160ws-aq-dio/diody-schottky-smd/diotec-semiconductor/sdb160ws-aq/) | YES
 | TVS | STS321150U751 | LINK (https://www.tme.eu/pl/details/sts321150u751-ea/diody-tvs-smd-jednokierunkowe/eaton-electronics/sts321150u751/) | YES | YES
 | Fuse | SN005-60 | LINK (https://www.tme.eu/pl/details/sn005-60/bezpieczniki-polimerowe-smd/ece/) | YES
MCU |  | STM32C011F4P6 | LINK (https://www.tme.eu/pl/details/stm32c011f4p6/mikrokontrolery-st/stmicroelectronics/) | YES
 |  |  |  |  |  |  | BRUTTO | BRUTTO
 | Element | Value | Footprint | Qty | Alerady have | Link | Cost/piece [PLN] | Cost per board | Ordered count | Ordered | Comment
 | Buzzer | Buzzer | LD-BZEL:LD-BZEL-T56-0505 | 1 | NO | LINK (https://www.tme.eu/pl/details/ld-bzel-t56-0505/sygnalizatory-elektromag-bez-generatora/loudity/) | 5.71 | 5.71 | 5 |  | Zamówiono zamiennik https://www.tme.eu/pl/details/ld-bzel-t54-0505/sygnalizatory-elektromag-bez-generatora/loudity/
 | Capacitor | 1u 25V | Capacitor_SMD:C_0603_1608Metric_Pad1.08x0.95mm_HandSolder | 3 | YES
 | Capacitor | 100n 50V | Capacitor_SMD:C_0603_1608Metric_Pad1.08x0.95mm_HandSolder | 5 | YES
 | Diode | SDB160WS-AQ | Diode_SMD:D_SOD-323 | 1 | NO | LINK (https://www.tme.eu/pl/details/sdb160ws-aq-dio/diody-schottky-smd/diotec-semiconductor/sdb160ws-aq/) | 0.7735 | 0.7735 | 5
 | TVS | STS321150U751 | Diode_SMD:D_SOD-323F | 5 | NO | LINK (https://www.tme.eu/pl/details/sts321150u751-ea/diody-tvs-smd-jednokierunkowe/eaton-electronics/sts321150u751/) | 0.7795 | 3.8975 | 25
 | Diode | 1N4148WSTR | Diode_SMD:D_SOD-323 | 3 | NO | LINK (https://www.tme.eu/pl/details/1n4148wstr-smc/diody-uniwersalne-smd/smc-diode-solutions/1n4148wstr/) | 0.1845 | 0.5535 | 15
 | Fuse | SN005-60 | Fuse:Fuse_1206_3216Metric_Pad1.42x1.75mm_HandSolder | 1 | NO | LINK (https://www.tme.eu/pl/details/sn005-60/bezpieczniki-polimerowe-smd/ece/) | 0.446 | 0.446 | 10
 | Connector | Conn_01x02_Socket | Connector_PinHeader_2.54mm:PinHeader_1x02_P2.54mm_Vertical | 2 | NO | LINK (https://www.tme.eu/pl/details/xy308-2p-2.54-gn/listwy-zaciskowe-do-druku/xinya/xy308-2p-2-54mm-green/) | 1.2349 | 2.4698 | 10
 | Connector | Conn_01x03_Socket | TerminalBlock_Phoenix:TerminalBlock_Phoenix_MKDS-1,5-3_1x03_P5.00mm_Horizontal | 1 | NO | LINK (https://www.tme.eu/pl/details/dg301-5.0-3p12/listwy-zaciskowe-do-druku/degson-electronics/dg301-5-0-03p-12-00z-h/) | 0.7048 | 0.7048 | 5
 | Connector | Conn_01x03_Socket | Connector_PinHeader_2.54mm:PinHeader_1x03_P2.54mm_Vertical | 1 | NO | LINK (https://www.tme.eu/pl/details/xy308-3p-2.54-gn/listwy-zaciskowe-do-druku/xinya/xy308-3p-2-54mm-green/) | 1.8635 | 1.8635 | 5
 | Relay | AZ921-1A-12DE | AZ921:AZ921 | 2 | NO | LINK (https://www.tme.eu/pl/details/az921-1a-12de/przekazniki-elektromagn-miniaturowe/zettler/) | 6.23 | 12.46 | 10
 | NMOS | BSS138 | Package_TO_SOT_SMD:SOT-323_SC-70 | 3 | NO | LINK (https://www.tme.eu/pl/details/bss138pw.115/tranzystory-z-kanalem-n-smd/nexperia/bss138pw-115/) | 0.5818 | 1.7454 | 20
 | Resistor | 100k | Resistor_SMD:R_0603_1608Metric_Pad0.98x0.95mm_HandSolder | 2 | YES
 | Resistor | 330R | Resistor_SMD:R_0603_1608Metric_Pad0.98x0.95mm_HandSolder | 7 | NO | LINK (https://www.tme.eu/pl/details/smd0603-330r/rezystory-smd/royalohm/0603saj0331t5e/) | 0.0375 | 0.2625 | 100
 | Resistor | 2K | Resistor_SMD:R_0603_1608Metric_Pad0.98x0.95mm_HandSolder | 4 | YES
 | LDO | LDK320M33R | Package_TO_SOT_SMD:SOT-23-5_HandSoldering | 1 | NO | LINK (https://www.tme.eu/pl/details/ldk320m33r/stabilizatory-napiecia-nieregulowane-ldo/stmicroelectronics/) | 1.4453 | 1.4453 | 10
 | MCU | STM32C011F4Px | Package_SO:TSSOP-20_4.4x6.5mm_P0.65mm | 1 | NO | LINK (https://www.tme.eu/pl/details/stm32c011f4p6/mikrokontrolery-st/stmicroelectronics/) | 4.08 | 4.08 | 6
 | Optoisolator 4x | LTV-247 | Package_SO:SOP-16_4.4x10.4mm_P1.27mm | 1 | NO | LINK (https://www.tme.eu/pl/details/ltv-247/transoptory-wyjscie-analogowe/liteon/) | 6.0627 | 6.0627 | 6
 |  |  |  |  |  |  |  | 42.4745

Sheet: NMOS
Used for: | Voltage [V] | Needed current [A] | Power [W]
Buzzer | 3.3 | 0.1 | 0.33
Relay | 12 | 0.0483333333333333 | 0.58
Max current | 0.1
Safety coefficient | 1.4
Maximum current | 0.14
N-MOS PARAMS:
Ud | 24
Id | 0.14
Wybrano:
BSS138PW
Ploss
Voltage [V] | 3.3
Current [A] | 0.0483333333333333
RdsOn [Ohm] | 1.5
Ploss | 0.00350416666666667 | W
 | 3.50416666666667 | mW
Temperature raise
Rthja | 400 | K/W
Δtj | 1.40166666666667 | °C
T25°C | 26.4016666666667

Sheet: LDO
Power consumption
Picked: | LDK320M33R | LINK (https://www.tme.eu/pl/details/ldk320m33r/stabilizatory-napiecia-nieregulowane-ldo/stmicroelectronics/)
 | [mA] | [A] |  | LDO parameters
MCU | 10 | 0.01 |  | Vin | 12 | [V]
BUZZER | 70 | 0.07 |  | Vout | 3.3 | [V]
OPTO | 5 | 0.005 |  | Rthja | 160 | K/W
Sum | 85 | 0.085 |  | Tj | 125 | °C
Temperature raise Normal mode |  |  | Temperature raise Config mode
Current | 0.015 | [A] |  | [s]
Ploss | 0.1305 | [W] | Ton | 0.2
Δtj | 20.88 | °C | Toff | 0.8
Tj25°C | 45.88 | °C | Pon | 0.7395 | [W]
 |  |  | Poff | 0.1305 | [W]
 |  |  | Pmean | 0.2523 | [W]
 |  |  | Δtj | 40.368 | °C
 |  |  | Tj25°C | 65.368 | °C

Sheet: POWER
Input voltage | 12 | Internal voltage | 3.3
Element | Current [A] | Element | Current [A]
Relay | 0.01 | MCU | 0.01
Internal | 0.0108333333333333 | Buzzer | 0.07
 |  | Opto | 0.05
Sum | 0.0208333333333333
 |  | Sum | 0.13

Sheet: Relay
Vdd | Operating voltage | 3.3
Igmax | Max CPU pin current [mA] | 20
Rg | Picked R (Ω) | 330
Css | Input capacitance | 3E-11 | pF
 | Signal frequency | 4000 | Hz
 | Pin current | 0.01 | Below 20 → ok
t | Gate charging RC | Rg * Css | 9.9 | ns
 | Turn-on time | 3*t | 29.7 | ns
 | Signal period | 250000 | ns
 | On-time % of period | 0.0001188

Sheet: DIGITAL INPUTS
VCC | 12 | V DC
R pullup | 1000 | Ω | Opto
 |  |  | Rtotal | 1000 | Ω
12 V current | 0.012 | A | Vf | 1.2 | V | Optocoupler diode Vf
Ploss | 0.144 | W | If | 0.0108 | A
P1206 | 0.25 | W |  | 10.8 | mA
0603 can be used. | TRUE

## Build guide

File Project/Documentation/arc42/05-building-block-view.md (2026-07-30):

# 5. Building Block View

> Rendered from `Project/Model/Architecture/base/BaseArchitecture.sysml`,
> `Project/Model/Architecture/functional/FunctionalArchitecture.sysml`,
> `Project/Model/Architecture/logical/{LogicalArchitecture,FunctionalAllocation}.sysml`,
> `Project/Model/Architecture/product/{ProductComponents,ProductInterfaces,ProductArchitecture,LogicalToProductAllocation}.sysml`.

## 5.0 Whitebox Overall System — Base Architecture (Level 0)

`BaseArchitecture::ShutterController` (satisfies `SystemIdea::systemIdea`) is
composed of five parts fixed at project start (SM-PRD-07), fully connected:

| Building Block | Purpose | Fulfilled Requirements (via allocation chain) |
|---|---|---|
| `ControlUnit` | Processes commands and determines shutter movement behaviour | REQ-F-01, REQ-F-08, REQ-Q-02, REQ-Q-03 |
| `MotorDriver` | Switches motor power circuits to drive the shutter up/down | REQ-F-04..06, REQ-Q-02, REQ-Q-03 |
| `WallSwitchInterface` | Receives commands from a locally connected wall switch | REQ-F-02, REQ-I-01 |
| `RemoteInterface` | Receives commands from an external automation/control system | REQ-F-03, REQ-I-02 |
| `PowerModule` | Converts/distributes electrical power to controller components | (no Logical counterpart, ADR-004; realized by `PowerSupplyModule` at Product layer) |

Connections: `controlLogic↔motorDriver`, `localInterface→controlLogic`,
`remoteInterface→controlLogic`, `powerSupply→{controlLogic, motorDriver,
localInterface, remoteInterface}`.

## 5.1 Level 1 — Functional Architecture

`FunctionalArchitecture::RollerShutterControllerFunctions` (technology-
independent, derived from `UseCaseActivities` via the FAS method) is composed
of 8 Functional Elements:

| Functional Element | Realizes (UCA) | Key Ports |
|---|---|---|
| `requestAcquisitionFunctions` | `ReceiveControlRequest` | `commandIn` (boundary), `commandOut` |
| `controlLogicFunctions` | `DetermineMovementRequest` | `commandIn`, `requestOut` |
| `movementSupervisionFunctions` | `SuperviseMovementStop` (wraps `MonitorStopCondition`/`MonitorUserInterruption`) | `commandIn`, `requestIn`, `timingIn`, `stopOut`, `modeEventIn` |
| `shutterControlFunctions` | `StartShutterMovement`, `StopShutterMovement` | `requestIn`, `stopIn`, `motorOut` (boundary), `shutterOut` (boundary) |
| `configurationControlFunctions` | `DetermineConfigurationMode`, `CheckConfigurationModeState`, `RejectConfigurationModeReentry`, `ActivateConfigurationModeFE`, `ExitConfigurationModeFE` | `commandIn`, `modeEventOut` |
| `timeCountingFunctions` | `CountActionTimeFE` | `shutterStateIn`, `durationOut` |
| `memoryFunctions` | `SaveCountedTime`, `LoadTimingProfile` | `durationIn`, `durationOut` |
| `userNotificationFunctions` | `DispatchConfigModeNotification` | `modeEventIn` |

**Internal connections (composite, numbered per model):** boundary
`controlInput`→`requestAcquisitionFunctions`; →`controlLogicFunctions` and
(fan-out) →`movementSupervisionFunctions` and →`configurationControlFunctions`;
`controlLogicFunctions`→`movementSupervisionFunctions` + `shutterControlFunctions`
(`MovementRequest` fan-out); `movementSupervisionFunctions`→`shutterControlFunctions`
(`StopRequest`); `shutterControlFunctions`→boundary (`MotorState`) and
→boundary+`timeCountingFunctions` (`ShutterState`); `timeCountingFunctions`→
`memoryFunctions` (`TravelTime`); `memoryFunctions`→`movementSupervisionFunctions`
(`TravelTime`); `configurationControlFunctions`→`userNotificationFunctions` and
(fan-out) →`movementSupervisionFunctions` (`ConfigModeEvent`).

## 5.2 Level 2 — Logical Architecture

`LogicalArchitecture::RollerShutterControllerLogicalComponents` — 6 components,
allocated (loosely) from the 8 Functional Elements per
`FunctionalAllocation::FunctionToLogicalComponent` (ADR-004):

| Logical Component | Base Counterpart (`:>`) | Realizes FE(s) |
|---|---|---|
| `LogicalLocalRequestInterface` | `WallSwitchInterface` | `requestAcquisitionFunctions` (local translation) |
| `LogicalRemoteRequestInterface` | `RemoteInterface` | `requestAcquisitionFunctions` (remote translation) |
| `LogicalControlUnit` | `ControlUnit` | `requestAcquisitionFunctions` (arbitration), `controlLogicFunctions`, `configurationControlFunctions`, `memoryFunctions` |
| `LogicalMovementSupervisor` | — (no Base counterpart, ADR-004) | `movementSupervisionFunctions`, `timeCountingFunctions` |
| `LogicalMotorDrive` | `MotorDriver` | `shutterControlFunctions` |
| `LogicalUserNotification` | — (no Base counterpart) | `userNotificationFunctions` |

`requestAcquisitionFunctions` is the one documented 1-FE-to-3-component split
(translation split by physical channel; arbitration requires simultaneous
visibility of both channels, hence `LogicalControlUnit`).

`LogicalControlUnit` is flagged in the model as the architectural
bottleneck (4 of 8 FEs, connected to all 5 of the other Logical components;
one of two components REQ-Q-02/REQ-Q-03 cross-cut, together with
`LogicalMotorDrive`) — Product Architecture is required to re-evaluate
splitting it (see §5.3).

Key inter-component flows: local/remote `LogicalRequestInterface.commandOut`
→ `LogicalControlUnit.{local,remote}CommandIn`; `LogicalControlUnit.
commandRelayOut` → `LogicalMovementSupervisor.commandIn`; `LogicalControlUnit.
requestOut` fan-out → `LogicalMovementSupervisor`/`LogicalMotorDrive`;
`LogicalMovementSupervisor.stopOut` → `LogicalMotorDrive.stopIn`;
`LogicalMotorDrive.shutterStateOut` → `LogicalMovementSupervisor.
shutterStateIn`; `LogicalMovementSupervisor.durationOut` →
`LogicalControlUnit.durationIn`; `LogicalControlUnit.modeEventOut` →
`LogicalUserNotification.modeEventIn` (fan-out) → `LogicalMovementSupervisor.
modeEventIn`.

## 5.3 Level 3 — Product Architecture

`ProductArchitecture::RollerShutterControllerProductComponents` — single
low-cost 8-bit MCU platform (ADR-006/ADR-007), realizing
`LogicalControlUnit`'s concentration concern by **software modularization**
rather than hardware fragmentation:

| Product Component | Type | Realizes (allocation) | Unit Cost (PLN) |
|---|---|---|---|
| `localRequestInterface` / `remoteRequestInterface` | `RequestInterfaceCircuit` (×2) | `LogicalLocalRequestInterface` / `LogicalRemoteRequestInterface` (signal conditioning) | 1.5 each |
| `controlMCU` | `ControlMCU` | Hosts 7 firmware modules (below) | 2.0 |
| `motorDriveRelayModule` | `MotorDriveRelayModule` | `LogicalMotorDrive` | 3.5 |
| `userNotificationBuzzer` | `AudibleNotificationBuzzer` | `LogicalUserNotification` (ADR-008) | 0.5 |
| `powerSupplyModule` | `PowerSupplyModule` (`:> BaseArchitecture::PowerModule`) | — (strong-coupled, no Logical counterpart) | 1.5 |
| `enclosureAndConnectors` | `EnclosureAndConnectors` | — (new mechanical element, no signal port) | 4.0 |

**Total: `totalUnitCostPLN` = 14.5** (asserted `≤ 50.0`, satisfying `costEffective`).

**Firmware modules hosted on `ControlMCU`** (LogicalControlUnit split,
closing the Level-2 follow-up):

| Firmware Module | Realizes | Coupling |
|---|---|---|
| `CommandArbitrationSoftware` | `LogicalLocalRequestInterface`/`LogicalRemoteRequestInterface` translation + `LogicalControlUnit` arbitration/conflict detection | Loose (allocation, ADR-007) |
| `MovementControlSoftware` | Remainder of `controlLogicFunctions` (arbitrated → `MovementRequest`) | Loose |
| `ConfigurationManagerSoftware` | `configurationControlFunctions` (+ wiring-mode selection) | Loose |
| `MemoryManagerSoftware` | `memoryFunctions` (EEPROM persistence of `TravelTime`, wiring mode) | Loose |
| `MovementSupervisorSoftware` | `LogicalMovementSupervisor` | Strong (`:>`) |
| `MotorDriveControlSoftware` | Relay coil drive logic | Loose |
| `UserFeedbackSoftware` | `LogicalUserNotification` (buzzer pattern arbitration) | Loose |

New Product-layer-only interfaces (`ProductInterfaces.sysml`, no earlier-layer
counterpart): `RelayControlPort` (relay coil drive), `BuzzerControlPort`
(ADR-008), `LogicPowerRailPort` (3.3 V regulated rail), `ProgrammingPort`
(manufacturing test/flash, REQ-Q-01).

`PowerSupplyModule` and `EnclosureAndConnectors` are the two Product
components with no Logical-to-Product allocation entry — both intentionally
justified (strong-coupled from Base, and a new mechanical-only element,
respectively; ADR-007).

## 5.4 Level 4 — Software Building Block View (SWA-03)

> Rendered from `Project/Model/Architecture/software/building_block_view/SWBuildingBlocks.sysml`.
> Continues Product Architecture one level deeper: internal structure,
> algorithms, and state-machine hosting for the firmware modules selected for
> whitebox decomposition (SWA-02's decomposition rationale, §4.5 above).

### State-machine hosting

`MovementSupervisorSoftwareInternal` (`:> MovementSupervisorSoftware`)
exhibits `SystemStates::ControllerLifecycleState` directly —
`exhibit state lifecycle : ControllerLifecycleState;` — reusing the state
machine's full body (defined once on the `state def` itself) without
duplicating it. The Logical-layer specialization
`RollerShutterControllerWithLifecycle` exhibits the same state def; both
hosts are deliberate, documented reuse (see `SystemStates.sysml`'s
dual-host summary), not accidental duplication.

### `CommandArbitrationSoftwareInternal` whitebox

| Element | Kind | Purpose |
|---|---|---|
| `ConfirmInputDebounce` | `action def` | Confirms a raw GPIO transition as genuine (stable ≥ `debounceConfirmMs`) rather than residual electrical noise; one instance per input line (`confirmLocalUp/Down`, `confirmRemoteUp/Down`) |
| `ArbitrateAndDetectConflict` | `action def` (specializes `ReceiveControlRequest`) | Refines the UC-level accept race with `arbitrationWindowMs`-based UP+DOWN conflict detection, forcing `direction := none` on a genuine conflict |
| `lastLocalEdgeMs` / `lastRemoteEdgeMs` | internal `attribute` | Per-channel last confirmed edge timestamp; flowed into `arbitrateChannels` as input data — the comparison algorithm itself stays SDD-deferred |

### `MovementControlSoftwareInternal` whitebox

Reuses `UseCaseActivities::DetermineMovementRequest` directly via
`perform action translateCommand : DetermineMovementRequest;` — command-to-
request translation is already fully specified at the Use Case Activities
level, so no further firmware-level refinement was needed.

### Driver / HAL layer (ADR-SW-011)

> Each driver is the sole owner of one hardware-facing port group, nested as
> a `part def` inside its owning module's `*Internal` whitebox. Drivers stay
> signature-free (name, responsibility, owning module, layer placement only)
> — API/method design is explicitly SDD scope.

| Driver | Owning module | Responsibility |
|---|---|---|
| `GpioInputDriver` | `CommandArbitrationSoftwareInternal` | Owns the four raw GPIO change-notification lines (ADR-SW-010); forwards raw, unconfirmed levels only |
| `TimerDriver` | `MovementSupervisorSoftwareInternal` | Owns the periodic timer peripheral (ADR-003/ADR-SW-009); produces `TimerTick`, routed via `eventDispatcher` |
| `MotorRelayOutputDriver` | `MotorDriveControlSoftwareInternal` | Sole owner of `upCoil`/`downCoil`; enforces break-before-make so both coils are never asserted together |
| `BuzzerOutputDriver` | `UserFeedbackSoftwareInternal` | Sole owner of the single `buzzerOn` drive line (ADR-008) |
| `EepromDriver` | `MemoryManagerSoftwareInternal` | Sole owner of `internalEepromBytes` read/write access (ADR-006, Cross-cutting Concept 4) |

No Application-level action references a hardware-facing port directly; each
goes through its module's driver only.

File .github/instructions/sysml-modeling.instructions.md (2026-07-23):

---
applyTo: "**/*.sysml"
---
# SysML v2 Modeling Instructions

When editing or creating `.sysml` files in this project:

## File Header Pattern

Every `.sysml` file must start with explicit imports. Follow the required import matrix in
`KnowledgeSource/integration/okf-ontology.md §6.3`. Standard pattern:

```sysml
package <PackageName> {
    private import <Dependency1>::*;
    private import <Dependency2>::*;

    // ... model elements follow
}
```

## Requirements Pattern

Use the two-layer pattern (see `KnowledgeSource/integration/crossmapping/requirements.md §2`):
- Layer 1: `requirement def` templates (category types: FunctionalReq, PerformanceReq, SafetyReq, InterfaceReq)
- Layer 2: `requirement` usages typed by those templates — these are the actual project requirements
- Annotate every requirement usage with `@RequirementMeta { source, priority, verificationMethod, rationale }`
- `satisfy` and `verify` always target requirement **usages**, never bare `requirement def` names

## Architecture Decomposition

Follow the 4-level decomposition from `KnowledgeSource/integration/okf-ontology.md §7`:
- L0: System Context — `part def`, `port def`, `connection def`
- L1: Functional Architecture — `part def` + `action def` + `flow def` (technology-independent)
- L2: Logical Architecture — `part def` + typed `port def` + `allocation def`
- L3: Product Architecture — concrete `part def` with `attribute` values + `satisfy` links

## System Context Rules

- Model actors as `part def` (not SysML `actor` element) — see `KnowledgeSource/sysmod/tools/death-of-actor.md`
- Use proxy ports exclusively (`port def`) — see `KnowledgeSource/sysmod/tools/proxy-versus-full-port.md`
- Every external interface must have a typed `port def` with `flow def` item types
- Every `connect` statement must reference typed ports

## Perform Action Pattern

Use `perform action <name> : <DefName>` to invoke use case defs or action defs by reference:
```sysml
perform action receiveRequest : ReceiveControlRequest;  // correct
action receiveRequest : ReceiveControlRequest { ... }   // only if adding parameter bindings
```

## Common Anti-Patterns to Avoid

- ❌ `requirement def REQ_001 { doc /* specific text */ }` — bare def with project-specific doc text
- ✅ `requirement <'REQ-001'> myReq : FunctionalReq { doc /* specific text */ }`
- ❌ Missing `import` statements causing unresolved-type errors
- ❌ `actor` keyword (SysML v1) — use `part def` instead
- ❌ Full ports — use `port def` (proxy ports) exclusively

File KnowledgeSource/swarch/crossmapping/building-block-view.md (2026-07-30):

---
okf_version: "0.1"
type: OKF Cross-Mapping
title: Cross-Mapping — Software Building Block View
description: Full SysML v2 and arc42 mapping for Software Architecture artifact Building Block View (SWA-03).
timestamp: 2026-07-01T00:00:00Z
---

# Cross-Mapping — Software Building Block View (SWA-03)

The Software Building Block View continues arc42's iterative Building Block
View (ARC-05) one level deeper than SYSMOD's Product Architecture (SM-PRD-21,
arc42 Level 3): it opens up each firmware `part def` blackbox to reveal its
internal sub-modules, algorithms, data, and exhibited state machines.

## §1 SysMod Definition

**Artifact ID:** SWA-03
**Not a SYSMOD product** — SYSMOD's own text states the next level of detail below Product Architecture is "part of specific engineering models... out of scope for the system model." SWA-03 is the project's own convention for keeping that engineering model inside the same SysML v2 model rather than switching tools.
**Continues:** [Product Architecture](../../sysmod/products/product-architecture.md) (SM-PRD-21) firmware `part def` components.
**Responsible Role:** Software Architect (project role).

### Purpose

To decompose selected firmware `part def` components (those complex enough
to warrant it, per arc42's own selectivity guidance) into their internal
structure: sub-modules, internal algorithms, internal data, and — critically
for this project — the concrete `exhibit state` binding of the System States
(SM-PRD-23) state machines that currently exist only on Logical-layer
specializations.

### Role in Process

Performed after the Software Solution Strategy (SWA-02) has assigned
decomposition rationale and state-machine hosts. For each firmware `part
def` selected for decomposition, the Software Architect creates a new
specializing `part def` (`:>` the existing component) and adds nested
`part`/`action`/`attribute` usages to it, plus, where assigned, the full
`exhibit state` body (state usages, transitions, entry/do/exit actions).

### Inputs (table)

| # | Input Artifact | ID | Description |
|---|---|---|---|
| 1 | Product Architecture | SM-PRD-21 | The firmware `part def` components being decomposed, with their existing ports/flows/attributes |
| 2 | Software Solution Strategy | SWA-02 | Decomposition rationale and state-machine hosting assignment |
| 3 | System States | SM-PRD-23 | The `state def` taxonomies to be exhibited on the assigned firmware host |
| 4 | Use Case Activities | SM-PRD-14 | `action def` bodies that may need firmware-level refinement |

### Outputs / Dependent Artifacts (table)

| # | Dependent Artifact | ID | Relationship |
|---|---|---|---|
| 1 | Software Runtime View | SWA-04 | Internal actions and exhibited states become scenario participants |
| 2 | Software Deployment View | SWA-05 | Internal data structures contribute to the RAM budget |
| 3 | Test Cases | SM-PRD-16 | Internal algorithms may need unit-level verification cases |

### Dependencies

- **SM-PRD-21 (Product Architecture):** Every SWA-03 decomposition MUST be added via a NEW `part def` that specializes (`:>`) an existing firmware `part def` unchanged — SysML v2 has no mechanism to "reopen" a `part def` and inject members into it from another package. SWA-03 never introduces a new top-level firmware component (that would be a Product Architecture change) and never re-declares an existing component's simple name as if extending it in place.
- **SWA-02 (Solution Strategy):** The state-machine host assignment from SWA-02 MUST be honoured exactly — `exhibit state` goes on the assigned (specializing) `part def`, not wherever is most convenient.

---

## §2 SysML v2 Mapping

### Mapping Table

| SW Architecture Element | SysML v2 Construct | Node ID | Rationale |
|---|---|---|---|
| Whitebox specialization | New `part def <Name>Internal :> <ExistingPartDef>` | [SML-META] [Subclassification](../../sysml2/concepts/subclassification.md) | SysML v2 has no partial-class/reopening mechanism; a NEW specializing `part def` inherits every existing port/attribute unchanged and is the only non-invasive way to add internal structure to an existing Product Architecture component |
| Internal sub-module | Nested `part def` / `part` usage inside the specializing `part def` | [SML-USG-PartUSG](../../sysml2/concepts/part-usage.md) | Same construct as L0–L3, applied one containment level deeper |
| Internal algorithm | `action def` + `perform action` | [SML-DEF-ActDef](../../sysml2/concepts/action-definition.md) | Reuses the same action pattern already used in Use Case Activities (SM-PRD-14) |
| Internal data structure | `attribute` usage (private/internal, not exposed via a port) | [SML-USG-AttrUSG](../../sysml2/concepts/attribute-usage.md) | Distinguishes internal state from the port-visible interface already fixed by the Product Architecture |
| State-machine hosting | `exhibit state <name> : <StateDef> {...}` | [SML-USG-StateUSG](../../sysml2/concepts/state-usage.md) | Identical mechanism already used in `SystemStates.sysml`; only the *host* `part def` changes (from a Logical specialization to the concrete firmware component's own specializing `part def`) |
| Whitebox diagram | Definition Diagram | [SML-DGM-DefDiag](../../sysml2/diagrams/definition-diagram.md) | One diagram per decomposed firmware component, showing its internal parts |

### Modeling Pattern

```sysml
package SWA_BuildingBlocks {
    private import ProductComponents::*;
    private import SystemStates::*;

    // Whitebox decomposition of MovementSupervisorSoftware (already a
    // Product Architecture part def). SysML v2 has no "reopening"/partial-
    // class mechanism — a second `part def MovementSupervisorSoftware { }`
    // declared in a different package would create an unrelated definition
    // that merely happens to share a simple name; it would NOT add members
    // to the original `ProductComponents::MovementSupervisorSoftware`. The
    // correct, non-invasive mechanism — already established in this project
    // (e.g. `SystemStates.sysml`'s `RollerShutterControllerWithLifecycle :>
    // RollerShutterControllerLogicalComponents`, and `ProductComponents`'
    // own `MovementSupervisorSoftware :> LogicalMovementSupervisor`) — is
    // subclassification (`:>`): a NEW specializing part def that inherits
    // every existing port/attribute unchanged and adds internal structure
    // alongside them.
    part def MovementSupervisorSoftwareInternal :> ProductComponents::MovementSupervisorSoftware {
        // ... every port/attribute already on MovementSupervisorSoftware is
        // inherited unchanged via ':>' — nothing is redeclared here ...

        // Internal sub-module: the timer-tick countdown algorithm.
        action def RunSupervisionTick {
            in elapsedMs : Real;
            out timedOut : Boolean;
        }

        // Internal data: current countdown state, not visible on any port.
        attribute remainingMs : Real;

        // Resolves the project's open state-machine-binding gap: the
        // firmware host now directly exhibits the state machine instead of
        // only a Logical-layer specialization doing so.
        exhibit state lifecycle : ControllerLifecycleState {
            // Body elaborated per SystemStates.sysml's existing pattern.
        }
    }

    // Package-level usage instantiating the specialized whitebox (mirrors
    // SystemStates.sysml's own package-level usage pattern for its
    // specializing part def) — this is what SWA-02's state-hosting
    // assignment would point ControlMCU's part usage at, if this component
    // is selected as the concrete firmware host.
    part movementSupervisorSoftwareInternal : MovementSupervisorSoftwareInternal;
}
```

### Recommended Package Structure

```
<System>_Architecture/
  software/
    building_block_view/
      <System>_SWBuildingBlocks.sysml   ← nested part/action/attribute additions per firmware component
```

---

## §3 arc42 Mapping

| arc42 Section | ID | Relationship | Content Contributed |
|---|---|---|---|
| [Building Block View](../../arc42/sections/building-block-view.md) | ARC-05 | **Mandatory** | Level 4+ whitebox decomposition of selected firmware components |
| [Runtime View](../../arc42/sections/runtime-view.md) | ARC-06 | Recommended | Exhibited state machines feed directly into runtime scenarios (SWA-04) |

---

## §4 Traceability

### Incoming Links (table)

| Source ID | Source Name | Link Type | Description |
|---|---|---|---|
| SM-PRD-21 | Product Architecture | `refines` | SWA-03 is a deeper whitebox refinement of an existing firmware `part def` |
| SWA-02 | Software Solution Strategy | `depends_on` | Decomposition rationale and state-hosting assignment must be followed |
| SM-PRD-23 | System States | `depends_on` | State taxonomies exhibited here are defined there |

### Outgoing Links (table)

| Target ID | Target Name | Link Type | Description |
|---|---|---|---|
| SWA-04 | Software Runtime View | `enables` | Internal actions/states become scenario participants |
| SWA-05 | Software Deployment View | `enables` | Internal data structures are counted in the RAM budget |
| ARC-05 | Building Block View | `documents` | Rendered as Level 4+ whitebox sub-sections |

### Traceability Rules

1. Every SWA-03 whitebox decomposition MUST be added via a NEW `part def` that specializes (`:>`) an existing Product Architecture firmware `part def` — never by re-declaring/nesting inside the original definition, and never as a sibling top-level component unrelated to it.
2. Every `exhibit state` added here MUST correspond to a hosting assignment already made in SWA-02.
3. Not every firmware component requires SWA-03 decomposition — omission MUST be a documented choice (e.g. in SWA-02's rationale), not a silent gap.

---

## §5 Modeling Procedure

1. **Select components to decompose.** From SWA-02's decomposition rationale, list the firmware `part def` components warranting whitebox detail (typically: any component with a non-trivial internal algorithm or an assigned state machine).

2. **Add internal sub-modules.** For each selected component, create a new specializing `part def` (`:> ExistingPartDef`) and add nested `part`/`action def` for its internal algorithms inside that specialization — the existing ports/attributes from the Product Architecture are inherited unchanged, never edited in place.

3. **Add internal data.** Add `attribute` usages for internal data not already exposed via a port.

4. **Bind state machines.** For each state-machine hosting assignment from SWA-02, add the full `exhibit state` body — reusing the `state def` taxonomy already defined in `SystemStates.sysml`, following its established transition/guard/entry-do-exit style.

5. **Draw the whitebox diagram.** One Definition Diagram per decomposed component, in the same style already used for Product Architecture diagrams.

6. **Validate against Use Case Activities.** Confirm every internal `action def` here either specializes or is consistent with the corresponding `action def` at the Use Case Activities level (SM-PRD-14) — no contradicting behaviour.

7. **Document in arc42.** Add each decomposed component as a numbered Level 4 sub-section under ARC-05, following the existing Level 1→2→3 pattern already used for Functional/Logical/Product Architecture.

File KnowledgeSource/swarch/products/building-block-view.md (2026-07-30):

---
type: Software Architecture Artifact
title: Software Building Block View
description: Deeper whitebox decomposition (Level 4+) of individual firmware part def components already identified in Product Architecture — internal modules, algorithms, and data structures.
timestamp: 2026-07-01T00:00:00Z
---

Artifact SWA-03. The Software Building Block View continues arc42's
Building Block View (ARC-05) below the level where the Product Architecture
(SM-PRD-21) stops — each firmware `part def` component becomes a whitebox
container whose internal structure (sub-modules, algorithms, data) is opened
up here.

# Purpose

The Product Architecture treats each firmware component (e.g.
`MovementSupervisorSoftware`) as an opaque blackbox with ports, flows, and
resource-estimate attributes. The Software Building Block View opens that
blackbox: what internal functions/algorithms does it contain, what internal
data does it hold, and how do its internal parts collaborate to realize the
ports already defined at the Product Architecture level?

# Description

This is a direct continuation of arc42's iterative Building Block View
pattern (Whitebox Level 1 → Level 2 → Level 3 → …), applied one level deeper
than SYSMOD's Product Architecture (which corresponds to arc42 ARC-05 Level
3). Concretely, for each firmware `part def` that is "complex enough to
warrant further decomposition" (arc42's own criterion), this artifact adds:

- Nested `part def`/`part` usages representing internal sub-modules.
- `action def`/`perform action` for internal algorithms (e.g. the
  first-wins arbitration logic, the debounce filter, the EEPROM
  wear-leveling routine).
- `attribute` usages for internal data structures (e.g. a ring buffer, a
  small state table) that are not visible as ports.
- `exhibit state` bindings, when a firmware module is the concrete host of
  a state machine already defined in System States (SM-PRD-23) — this is
  the resolution point for the current model gap where
  `ControllerLifecycleState` is exhibited only on a Logical-layer
  specialization (`RollerShutterControllerWithLifecycle`), not yet on any
  Product-layer firmware `part def`.

Not every firmware component needs this level of detail — apply it only
where internal complexity, safety criticality, or reuse potential justifies
it (same selectivity principle arc42 uses for whitebox depth).

# Relationships

**Responsibility:** Software Architect (project role).

**Primary Inputs:**
- [Product Architecture](../../sysmod/products/product-architecture.md) (SM-PRD-21) — the firmware `part def` components being decomposed.
- [Software Solution Strategy](solution-strategy.md) (SWA-02) — decomposition rationale and state-machine binding strategy.
- [System States](../../sysmod/products/system-states.md) (SM-PRD-23) — state machines to be exhibited on firmware parts.
- [Use Case Activities](../../sysmod/products/use-case-activities.md) (SM-PRD-14) — `action def` bodies already defined at the functional level may be refined here.

**Outputs consumed by:**
- [Software Runtime View](runtime-view.md) (SWA-04) — internal actions/parts appear as participants in runtime scenarios.
- [Software Deployment View](deployment-view.md) (SWA-05) — internal data structures contribute to the RAM budget.
- [Test Cases](../../sysmod/products/test-cases.md) (SM-PRD-16) — internal algorithms may need unit-level verification cases.

**Representation:** Nested `part def`, `action def`, `attribute usage`, `exhibit state` inside a NEW `part def` that specializes (`:>`) the existing firmware `part def` — SysML v2 has no partial-class/reopening mechanism, so the whitebox detail is added via subclassification (e.g. `part def MovementSupervisorSoftwareInternal :> MovementSupervisorSoftware { ... }`), never by re-declaring the original component's name — no new SysML v2 concepts beyond what L0–L3 already use.

**Cross-mapping:** [crossmapping/building-block-view.md](../crossmapping/building-block-view.md)

# Citations

- arc42 Architecture Documentation Framework, Section 5 (Building Block View) — iterative whitebox/blackbox pattern this artifact continues.
- SYSMOD – The Systems Modeling Toolbox, 3rd edition. Tim Weilkiens, MBSE4U, 2020. Section 5.21 (Product Architecture — states the next level of detail is out of scope for SYSMOD).

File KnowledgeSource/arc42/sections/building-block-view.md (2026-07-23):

---
type: arc42 Section
title: Building Block View
description: Describes the static decomposition of the system into building blocks arranged in hierarchical whitebox and blackbox levels.
timestamp: 2026-07-01T00:00:00Z
---

The Building Block View is the central structural section of an arc42 document. It describes how the system is decomposed into building blocks — components, modules, subsystems, or classes — arranged in a containment hierarchy. Each level of the hierarchy refines the previous one: higher levels show less detail (blackboxes), while lower levels open selected blackboxes to reveal their internal structure (whiteboxes).

The first level, Whitebox Overall System, presents the system as a whole opened up to reveal its top-level building blocks. Each building block at this level is a blackbox from the perspective of its container, and is described with its purpose, interfaces, and optionally its quality characteristics, directory location, and fulfilled requirements. Subsequent levels (Level 2, Level 3, …) progressively decompose selected building blocks, each time showing a whitebox view of one component from the level above.

Architects use this section as the primary reference for understanding static structure. It supports onboarding, impact analysis, and architectural reviews by providing a consistent map of all system components and their relationships. The number of levels documented should be driven by the complexity of the system and the communication needs of the audience.

# Schema

| Level | Elements |
|---|---|
| Whitebox Overall System | Overview Diagram; Motivation (text explanation); Contained Building Blocks (list/description of blackboxes); Important Interfaces |
| Black Box Template | Purpose/Responsibility; Interface(s); Optional: Quality/Performance Characteristics, Directory/File Location, Fulfilled Requirements, Open Issues/Problems/Risks |
| Level 2 | One whitebox description per building block from Level 1 that warrants further decomposition |
| Level 3 | One whitebox description per building block from Level 2 that warrants further decomposition |

**Black box description fields:**

| Field | Required | Description |
|---|---|---|
| Purpose/Responsibility | Yes | What this building block does |
| Interface(s) | Yes | How it communicates with the rest of the system |
| Quality/Performance Characteristics | No | Relevant non-functional properties |
| Directory/File Location | No | Where the implementation lives in the repository |
| Fulfilled Requirements | No | Which requirements this building block satisfies |
| Open Issues/Problems/Risks | No | Known issues or risks associated with this block |

# Relationships

* [Runtime View](runtime-view.md) — Building block instances from this section appear as participants in runtime scenarios in Section 6.
* [Deployment View](deployment-view.md) — Building blocks defined here are mapped to infrastructure nodes in Section 7.
* [Context and Scope](context-and-scope.md) — External interfaces visible at the system boundary in Section 3 are implemented by top-level building blocks here.

# Citations

[1] [arc42 Template](../references/arc42-template.md)

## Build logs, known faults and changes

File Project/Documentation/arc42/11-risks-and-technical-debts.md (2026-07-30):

# 11. Risks and Technical Debt

> Rendered from `Project/Model/Analysis/risks/Risks.sysml`
> (`@RiskMeta`: probability × impact → severity matrix) and
> `// GAP:` comments in `Project/Model/Architecture/scenarios/Scenarios.sysml`.

## Risk Register

| ID | Category | Risk | Prob. | Impact | Severity | Status | Owner | Mitigation |
|---|---|---|---|---|---|---|---|---|
| RISK-T-01 | Technical | Positioning drift (no position feedback → cumulative timing error) | medium | medium | **major** | open | System Architect | +5s open/close margin (`timingMarginS`); see [08](08-cross-cutting-concepts.md) Concept 2 |
| RISK-T-03 | Technical | Motor relay/triac wear-out under repeated switching | medium | medium | **major** | open | Hardware Engineer | ≥10,000-cycle rated components; validated by `TC_Q_003_ReliabilityEndurance` |
| RISK-T-04 | Technical | Shutter motor type incompatibility (speed/torque variance defeats one fixed timing profile) | medium | medium | **major** | open | System Architect | Per-installation configurable `TravelTime`; validated by `TC_F_012_ConfigurableTimingProfile_Nominal` |
| RISK-T-05 | Technical | Installer misconfiguration during timing calibration | medium | low | **minor** | open | System Architect | Guided config-mode procedure + out-of-range calibration rejection (`RejectOutOfRangeCalibration`, Scenarios::SCEN_22); validated by `TC_Q_001_InstallationTime` |
| RISK-S-01 | Safety | Insufficient galvanic isolation → electric shock hazard | low | high | **critical** (escalated) | open | Safety Engineer | Mandatory `motorIsolation`/`inputIsolation` constraints; validated by `TC_B_001`/`TC_B_002`/`TC_B_006` |
| RISK-B-01 | Business | Isolation/switching-load components push unit cost above 50 PLN target | medium | medium | **major** | open | Project Manager | Early sourcing engagement; track vs. `Business::costEffective` |
| RISK-I-01 | Integration | Wall-switch wiring topology incompatibility (momentary vs. latching) | medium | medium | **major** | open | System Architect | Documented topologies + configurable input mode; validated by `TC_F_002`/`TC_F_003` |

**Note on severity escalation (RISK-S-01):** the standard probability×impact
matrix would yield *major* for low×high; severity is escalated one level to
**critical** by explicit project convention whenever impact is a
safety-of-life hazard (ALARP-style treatment), per the risk's own
`rationale` field.

**Note on numbering:** there is no `RISK-T-02` — a gap in the ID sequence in
`Risks.sysml`, not a missing/removed risk.

All 7 risks remain `status = open`; none are `mitigated` or `closed` in the
current model.

## Technical Debt (Documented Model Gaps)

Explicit `// GAP:` comments in `Scenarios.sysml` mark intentionally
unresolved modeling detail — deferred by choice, not defect:

| Scenario | Gap |
|---|---|
| SCEN_15 (`PowerLoss_DuringMovement`) | No Logical/Product component observes, logs, or reacts to a control-power interruption; relay de-energization is a passive electrical consequence, not modeled behavior. No distinction between "stopped by timeout" and "stopped by power loss." |
| SCEN_16 (`PowerRecovery_AfterOutage`) | No modeled function re-establishes the shutter's physical position after power loss/recovery (ADR-003's no-position-feedback decision means no sensor exists to query); firmware boot/re-init is inferred generic MCU behavior, not a traceable model element. |
| SCEN_17 (`MechanicalJam_TimeBasedStopWithoutFeedback`) | No fault classification, indication, or recovery mechanism distinguishes a mid-travel mechanical jam from normal end-of-travel completion; the only recovery path is user-initiated re-calibration. |
| SCEN_21 (`DisposeController_EndOfLife`) | `UseCaseActivities::DisposeController` remains an intentionally underspecified single-action stub at the UCA layer (UC_05); the disposal scenario's steps are inferred from UC_05 metadata rather than a decomposed UCA. |
| SCEN_23 (`LocalControl_WiringModeMismatch`) | No existing UCA action models wiring-mode-mismatch **detection** specifically (recorded three times — in the scenario's header doc, step `s3`, and the trailing scenario-level comment); closest anchor is `HandleConflictingMovementCommands`. |

SCEN_05's former gap (no structural owner for the "latched-stopped-until-release"
guard) was resolved by the Software Architecture remediation (SWR-022/SWR-030):
`ProductComponents::CommandArbitrationSoftware` is the named owner — see
`Architecture/states/SystemStates.sysml`'s `MovingManual` doc.

These gaps are cross-cutting with RISK-T-01 (SCEN_15, SCEN_17) and
RISK-I-01 (SCEN_23) — they are the concrete scenario-level manifestations
of the risk register's open items, not independent defects.

## Software Architecture Technical Debt

- **ADR prose tightening (deferred by design):** `ADR_009_SWExecutionModel`
  and `ADR_010_InputDebouncing` match the existing `ADR_001`–`008` prose
  style (4–8 sentence fields) rather than a tighter target. This is a
  deliberate, documented deferral (`Architecture/software/REMEDIATION_PLAN.md`
  item 17) — retroactively tightening every existing ADR's prose is a
  separate, explicitly-scoped cleanup pass, not silently dropped.

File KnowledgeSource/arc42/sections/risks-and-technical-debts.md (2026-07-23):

---
type: arc42 Section
title: Risks and Technical Debts
description: Identifies known technical risks and accumulated technical debt that may affect the system's quality or evolvability.
timestamp: 2026-07-01T00:00:00Z
---

The Risks and Technical Debts section provides an honest assessment of the architectural weaknesses that exist in the system — either as risks that may materialise in the future or as technical debt that has already been consciously deferred. Documenting these explicitly is a mark of architectural maturity: it signals that the team is aware of the compromises made and has chosen to record rather than hide them.

Technical risks are potential problems that have not yet occurred but could have a significant impact on the system's quality, delivery timeline, or operational stability. They typically arise from reliance on unproven technologies, tight coupling at key integration points, or decisions made under time pressure that introduced fragility. Technical debts are known shortcomings in the current implementation — suboptimal designs, missing tests, or deprecated dependencies — that will need to be addressed to preserve the system's long-term health.

Architects use this section as a risk register and debt backlog. Each entry should describe the issue clearly, estimate its potential impact, and where possible suggest a mitigation or remediation path. Keeping this section current supports informed decision-making in planning and prevents the gradual accumulation of invisible complexity.

# Schema

| Element | Description |
|---|---|
| Risk / Debt title | A short descriptive name identifying the issue |
| Description | What the risk or debt is and how it arose |
| Impact | The potential consequences if the risk materialises or the debt remains unaddressed |
| Mitigation / Remediation | Actions that could reduce the risk or resolve the debt |

| Category | Description |
|---|---|
| Technical risk | A potential future problem that may affect quality, stability, or delivery |
| Technical debt | A known current shortcoming deferred for later remediation |

# Relationships

* [Architecture Decisions](architecture-decisions.md) — Some risks and debts result directly from trade-off decisions recorded in Section 9.
* [Quality Requirements](quality-requirements.md) — Risks may threaten the satisfaction of quality scenarios defined in Section 10.

# Citations

[1] [arc42 Template](../references/arc42-template.md)

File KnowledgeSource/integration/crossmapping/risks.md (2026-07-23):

---
okf_version: "0.1"
type: OKF Cross-Mapping
title: Cross-Mapping — Risks
description: Full SysML v2 and arc42 mapping for SYSMOD product Risks (SM-PRD-09).
timestamp: 2026-07-01T00:00:00Z
---

# Cross-Mapping — Risks (SM-PRD-09)

Risks are identified threats to achieving the system objectives or delivering a safe and correct system. The Risks product is a structured risk register modeled in SysML v2 as annotated `requirement def` elements — treating risks as "conditions the system must avoid or handle" — enabling `satisfy` links from mitigation measures. Each risk is characterized by probability, impact, severity, and mitigation strategy, and the register populates the mandatory arc42 ARC-11 section.

## §1 SysMod Definition

**Product ID:** SM-PRD-09
**SYSMOD §:** 5.9
**Process:** [Analysis](../../sysmod/processes/analysis-process.md) (SM-PRC-1)
**Creating Method:** [4.9 Model Risks](../../sysmod/methods/model-risks.md) (SM-MTH-09)
**Responsible Role:** [Requirements Engineer](../../sysmod/roles/requirements-engineer.md)

### Purpose

The Risks product captures and structures all identified threats that could prevent the system from meeting its objectives, satisfying safety requirements, or being delivered on time and within budget. By modeling risks formally in SysML v2, engineers can link risks to the specific model elements they affect, enabling impact analysis when design decisions change and providing a formal basis for deriving risk-driven requirements in SM-PRD-10.

### Role in Process

In the Analysis process (SM-PRC-1), risks are identified after the System Objectives (SM-PRD-06) are defined, since risks must be assessed against the goals they threaten. The Risks product informs Requirements (SM-PRD-10) by generating risk-driven requirements (e.g., safety requirements to mitigate critical risks), and informs Logical Architecture (SM-PRD-20) by highlighting which design decisions require mitigation measures.

### Inputs

| # | Input Product | ID | Description |
|---|---|----|---|
| 1 | System Idea | SM-PRD-05 | Defines the envisioned solution, introducing technology-specific risks |
| 2 | System Objectives | SM-PRD-06 | Provides the goals against which risk impact is measured and calibrated |

### Outputs / Dependent Artifacts

| # | Dependent Product | ID | Relationship |
|---|---|----|---|
| 1 | Requirements | SM-PRD-10 | Critical and major risks generate risk-driven requirements (safety, fault tolerance) |
| 2 | Logical Architecture | SM-PRD-20 | Architectural decisions must demonstrably address risks with `severity = "critical"` |

### Dependencies

The Risks product depends on SM-PRD-05 (System Idea) for technology-specific risk identification and SM-PRD-06 (System Objectives) for impact calibration. It does not depend on SM-PRD-07 through SM-PRD-08 directly, though stakeholder concerns (SM-PRD-08) can be reviewed as a secondary input for identifying business and compliance risks.

---

## §2 SysML v2 Mapping

### Mapping Table

| SYSMOD Element | SysML v2 Construct | Node ID | Rationale |
|---|---|---|---|
| Risk item | `requirement def Risk_<Name> { doc /.../ }` | [SML-DEF-ReqDef](../../sysml2/concepts/requirement-definition.md) | Risk modeled as a requirement — "the system must avoid or mitigate X" — enabling formal `satisfy` links from mitigation measures |
| Risk attributes (probability, impact, severity, etc.) | `metadata def RiskMeta { ... }` | [SML-DEF-MetaDef](../../sysml2/concepts/metadata-definition.md) | Structured metadata captures all risk assessment fields without extending the SysML type system |
| Risk-to-model-element link | `satisfy` (or documentation note reference) | [SML-USG-Satisfy](../../sysml2/concepts/satisfy.md) | Links the risk `requirement def` to the design element it affects; supports impact analysis |
| Risk register visualization | Requirements Diagram | [SML-DGM-ReqDiag](../../sysml2/diagrams/requirements-diagram.md) | Displays risk `requirement def` hierarchy with `@RiskMeta` annotations and mitigation links |
| Risk category grouping | `package <Category>Risks { ... }` | [SML-DEF-Package](../../sysml2/concepts/package.md) | Groups risks by category (technical, schedule, safety, integration) for management and filtering |
| Mitigation measure as derived requirement | `requirement def Mitigation_<Name>` | [SML-DEF-ReqDef](../../sysml2/concepts/requirement-definition.md) | Mitigation measures formally expressed as derived requirements in SM-PRD-10; linked via `satisfy` |

### Modeling Pattern

```sysml
package VehicleSystem_Risks {

  metadata def RiskMeta {
    attribute probability : String;  // high | medium | low
    attribute impact      : String;  // high | medium | low
    attribute severity    : String;  // critical | major | minor
    attribute mitigation  : String;
    attribute status      : String;  // open | mitigated | closed
    attribute riskOwner   : String;
  }

  package TechnicalRisks {

    requirement def Risk_CommunicationBusLatency {
      doc /* CAN FD latency may exceed real-time constraints under high bus load,
             causing delayed braking commands with direct safety implications. */
      @RiskMeta {
        probability = "medium";
        impact      = "high";
        severity    = "critical";
        mitigation  = "Define bus load budget ≤ 60%; use time-triggered scheduling for safety messages";
        status      = "open";
        riskOwner   = "System Architect";
      }
    }

    requirement def Risk_ECUTemperatureExceedance {
      doc /* ECU operating temperature may exceed 85°C in high-ambient desert conditions,
             causing computational errors or protective shutdown. */
      @RiskMeta {
        probability = "low";
        impact      = "high";
        severity    = "major";
        mitigation  = "Add thermal derating model; specify cooling requirements in Product Architecture";
        status      = "open";
        riskOwner   = "Hardware Engineer";
      }
    }
  }

  package ScheduleRisks {

    requirement def Risk_SupplierDeliveryDelay {
      doc /* ECU hardware prototype delivery from supplier may be delayed by 4–8 weeks,
             impacting integration testing schedule and product launch date. */
      @RiskMeta {
        probability = "medium";
        impact      = "medium";
        severity    = "major";
        mitigation  = "Arrange hardware-in-the-loop simulation environment as integration test fallback";
        status      = "open";
        riskOwner   = "Project Manager";
      }
    }
  }

  package SafetyRisks {

    requirement def Risk_SinglePointFaultUndetected {
      doc /* A single-point hardware fault in the braking ECU may go undetected beyond the
             10 ms fault detection window, violating ASIL-D requirements. */
      @RiskMeta {
        probability = "low";
        impact      = "high";
        severity    = "critical";
        mitigation  = "Implement dual-channel fault detection with cross-comparison; validate via FMEA";
        status      = "open";
        riskOwner   = "Safety Engineer";
      }
    }
  }
}
```

### Recommended Package Structure

```
<System>_Analysis/
└── risks/
    ├── <System>_Risks.sysml            # Top-level risk package with RiskMeta def
    ├── <System>_TechnicalRisks.sysml   # Technical risk sub-package
    ├── <System>_ScheduleRisks.sysml    # Schedule/project risk sub-package
    └── <System>_SafetyRisks.sysml      # Safety risk sub-package
```

---

## §3 arc42 Mapping

| arc42 Section | ID | Mandatory? | Content Mapped from SM-PRD-09 |
|---|---|---|---|
| [Risks and Technical Debts](../../arc42/sections/risks-and-technical-debts.md) | ARC-11 | **Mandatory** | Complete risk register table: Risk ID, description, probability, impact, severity, mitigation, status, owner |
| [Architecture Decisions](../../arc42/sections/architecture-decisions.md) | ARC-09 | Recommended | Risks with `severity = "critical"` that drove architectural decisions are referenced in ADRs |
| [Introduction and Goals](../../arc42/sections/introduction-and-goals.md) | ARC-01 | Optional | Critical risks summary may be noted in the quality goals section as known constraints |

**ARC-11 Risk Register Table format:**

| Risk ID | Description | Probability | Impact | Severity | Mitigation | Status | Owner |
|---|---|---|---|---|---|---|---|
| RISK-T-01 | CAN FD latency exceeds real-time constraints | medium | high | critical | Bus load ≤ 60%; time-triggered scheduling | open | System Architect |
| RISK-T-02 | ECU temperature exceedance in high-ambient environment | low | high | major | Thermal derating; cooling spec in PA | open | HW Engineer |
| RISK-S-01 | Supplier hardware delivery delay | medium | medium | major | HIL simulation fallback environment | open | Project Manager |
| RISK-S-02 | Single-point fault undetected beyond 10 ms window | low | high | critical | Dual-channel detection; FMEA validation | open | Safety Engineer |

---

## §4 Traceability

### Incoming Links

| Source Product | ID | Link Type | Description |
|---|---|---|---|
| System Idea | SM-PRD-05 | `depends_on` | Technology choices in the system idea introduce technology-specific and integration risks |
| System Objectives | SM-PRD-06 | `depends_on` | Objectives define the impact scale against which risk severity is calibrated |

### Outgoing Links

| Target Product | ID | Link Type | Description |
|---|---|---|---|
| Requirements | SM-PRD-10 | `refines` | Critical and major risks generate risk-driven requirements (safety, fault tolerance, performance) |
| Logical Architecture | SM-PRD-20 | `refines` | Architectural decisions must demonstrably address every risk with `severity = "critical"` |
| arc42 ARC-11 | ARC-11 | `documents` | Risk register populates the Risks and Technical Debts section |
| arc42 ARC-09 | ARC-09 | `documents` | Architecture decisions driven by critical risks are recorded as ADRs referencing risk IDs |

### Traceability Rules

1. Every `requirement def` in the risks package MUST have `@RiskMeta` with all fields populated (probability, impact, severity, mitigation, status, riskOwner).
2. Every risk with `severity = "critical"` MUST have at least one corresponding requirement in SM-PRD-10 addressing its mitigation (derived requirement pattern).
3. Every risk with `severity = "critical"` that drove an architectural decision MUST have a corresponding ADR in ARC-09 referencing the risk ID.
4. Every risk entry in the SysML model MUST appear as a row in the ARC-11 risk register table with identical IDs.
5. Risk `status` field MUST be kept current; mitigated risks MUST reference the specific requirement or design element (`satisfy` link target) that provides the mitigation.

---

## §5 Modeling Procedure

1. **Seed the risk list from objectives and system idea.** Review SM-PRD-06 (objectives) to identify which goals are at risk, and SM-PRD-05 (system idea) to identify technology-specific risks. Consult historical risk databases and lessons-learned from analogous projects.
2. **Define the `RiskMeta` metadata definition.** Establish `metadata def RiskMeta` with fields for probability, impact, severity, mitigation, status, and riskOwner in the top-level risks package. This ensures consistent structure across all risk entries.
3. **Create risk sub-packages by category.** Organize risks into sub-packages: TechnicalRisks, ScheduleRisks, SafetyRisks, IntegrationRisks. This supports filtering, prioritization, and role-based review.
4. **Model each risk as a `requirement def`.** For each identified risk, create a `requirement def Risk_<Name>` with a `doc` string describing the threat in the format: "[Cause] may result in [effect], leading to [consequence for system objectives]."
5. **Annotate each risk with `@RiskMeta`.** Fill in all fields: probability (high/medium/low), impact (high/medium/low), severity (critical/major/minor — derived from probability × impact matrix), mitigation strategy, status (open), and riskOwner.
6. **Assess severity using a risk matrix.** Apply a standard risk matrix: high probability + high impact = critical; low probability + high impact = major; other combinations yield major or minor. Document the rationale for the severity assignment explicitly in the `@RiskMeta.mitigation` field context.
7. **Link risks to affected model elements.** Using `satisfy` relationships or documentation notes, link each risk `requirement def` to the `part def`, `requirement def`, or interface element it threatens. This enables downstream impact analysis when design decisions change.
8. **Derive risk-driven requirements.** For every risk with `severity = "critical"` or `"major"`, derive at least one requirement in SM-PRD-10 that specifies what the system must do to prevent or mitigate the risk. Cross-reference the risk ID in `@RequirementMeta.source`.
9. **Populate ARC-11.** Transfer all risk entries to the arc42 Risks and Technical Debts section (ARC-11) in the standard risk register table format. Risk IDs must match between the SysML model and the arc42 document.
10. **Write ADRs for architecture decisions driven by critical risks (ARC-09).** For each critical risk that caused a specific architectural design decision (e.g., choosing time-triggered scheduling to mitigate bus latency), write a corresponding ADR in ARC-09 referencing the risk ID and explaining how the decision reduces probability, impact, or severity.

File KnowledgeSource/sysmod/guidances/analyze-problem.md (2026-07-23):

---
type: SYSMOD Guidance
title: How to Analyze the Problem
description: A step-by-step guide for analyzing and documenting the problem statement, including use of the Problem Statement model template and workshop tools for problem space exploration.
timestamp: 2026-07-01T00:00:00Z
---

Guidance 7.2 in SYSMOD. This guidance describes how to model the Problem Statement in the SysML model.

# Context

- **SYSMOD Method:** [4.5 Analyze the Problem](../methods/analyze-problem.md)
- **SYSMOD Product:** [5.4 Problem Statement](../products/problem-statement.md)
- **SYSMOD Role:** [Project Manager](../roles/project-manager.md)

# Description

The Problem Statement is stored in the model as a property of the SYSMOD stereotype «system». The 6M and Five Whys workshop tools can be used to analyze the problem space before creating the Problem Statement. The Problem Statement summarizes the conclusions of this analysis.

The Problem Statement document template contains the fields: Who is having the problem, What is the problem and the context, and Why it matters.

# How to Model

1. Select the system element in the root package of the core.
2. The SYSMOD stereotype «system» has a property `problemStatement` to store the Problem Statement. Enter the text of the Problem Statement in this field. If the Problem Statement refers to external documents, put a reference to the external source in the model.

# Citations

- SYSMOD – The Systems Modeling Toolbox, 3rd edition. Tim Weilkiens, MBSE4U, 2020. Section 7.2.

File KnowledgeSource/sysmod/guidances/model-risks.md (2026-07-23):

---
type: SYSMOD Guidance
title: How to Model Risks
description: A step-by-step guide for modeling risks in the SysML model using SYSMOD risk elements in a table view within the system model.
timestamp: 2026-07-01T00:00:00Z
---

Guidance 7.7 in SYSMOD. This guidance describes how to model Risks in the SysML system model.

# Context

- **SYSMOD Method:** [4.9 Model Risks](../methods/model-risks.md)
- **SYSMOD Product:** [5.9 Risks](../products/risks.md)
- **SYSMOD Role:** [Requirements Engineer](../roles/requirements-engineer.md)

# Description

Each Risk is documented in a table to store the information in a uniform structured format. The Risk model elements are created as SYSMOD risk elements in the dedicated Risks package.

# How to Model

1. Select the package `<system>Risks`.
2. Create a table to depict the Risks.
3. For each identified Risk, create an appropriate SYSMOD risk element and fill out its properties.

# Citations

- SYSMOD – The Systems Modeling Toolbox, 3rd edition. Tim Weilkiens, MBSE4U, 2020. Section 7.7.

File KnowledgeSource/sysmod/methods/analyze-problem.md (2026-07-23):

---
type: SYSMOD Method
title: Analyze the Problem
description: Find out the real problem that should be resolved by the system by performing a profound analysis beyond the initial problem statement.
timestamp: 2026-07-01T00:00:00Z
---

Method 4.5 in SYSMOD. Sometimes the initial problem statement does not represent the real problem—a profound analysis is required to identify the true challenge. Design Thinking and problem-solving frameworks support this method.

# Purpose

Find out the real problem that should be resolved by the system. Sometimes it is not the initial problem statement, and the real problem must be identified by a profound analysis.

# Description

An illustrative example of the importance of finding the real problem is the quote attributed to Henry Ford: "If I had asked my customers what they wanted, they would have said a faster horse." The real problem to be solved and the real needs to be satisfied require a profound analysis.

Design Thinking is an approach to solve problems creatively with a particular focus on problem analysis. Part of the Design Thinking process is the redefinition of the initial problem statement to find the real challenge that satisfies the needs of the stakeholders. Design Thinking asks what the users need, not just what they want.

Another approach is the problem-solving process described by Reinhard Haberfellner et al., based on five steps of problem-solving by John Dews (1910). The process is logical rather than strictly sequential, with many feedback cycles.

Two simple workshop tools to explore the problem space are the 6M and Five Whys methods.

# Relationships

**Primary Performer:** [Project Manager](../roles/project-manager.md)

**Inputs:** None

**Outputs:**
- [5.4 Problem Statement](../products/problem-statement.md)

**ISO 15288 Process:** Business Mission Analysis

**Guidance:**
- [7.2 How to Analyze the Problem](../guidances/analyze-problem.md)

**Part of Process:**
- [SYSMOD Analysis Process](../processes/analysis-process.md)

**Related Tools:**
- [Workshop Tool: 6M Method](../tools/6m-method.md)
- [Workshop Tool: Five Whys Method](../tools/five-whys-method.md)

# Citations

- SYSMOD – The Systems Modeling Toolbox, 3rd edition. Tim Weilkiens, MBSE4U, 2020. Section 4.5.

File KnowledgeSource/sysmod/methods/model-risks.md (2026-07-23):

---
type: SYSMOD Method
title: Model Risks
description: Specify the business, organizational, and technical risks in the system model and link them to other model elements for traceability.
timestamp: 2026-07-01T00:00:00Z
---

Method 4.9 in SYSMOD. The Risks specify the potential inability to achieve the System Objectives. They are linked to other model elements to provide traceability to and from the Risks.

# Purpose

The Risks specify the potential inability to achieve the System Objectives. They are linked to other model elements to provide traceability to and from the Risks.

# Description

Risk Management is an important topic in itself and is only dealt with to a small extent by SYSMOD. This method only specifies the Risks in the model and links them to other model elements, but does not cover the entire Risk Management process.

The System Idea and System Objectives inputs are intended for the initial setup of the Risks. Later, Risks are also derived from the System Architectures.

For lightweight risk management, the SYSMOD modeling of the Risks could be sufficient. If the Risks are managed in an external risk management tool, the Risks in the model are proxies to establish links and traceability to other model elements.

# Relationships

**Primary Performer:** [Requirements Engineer](../roles/requirements-engineer.md)

**Inputs:**
- [5.5 System Idea](../products/system-idea.md)
- [5.6 System Objectives](../products/system-objectives.md)

**Outputs:**
- [5.9 Risks](../products/risks.md)

**ISO 15288 Process:** Risk Management

**Guidance:**
- [7.7 How to Model Risks](../guidances/model-risks.md)

**Part of Process:**
- [SYSMOD Analysis Process](../processes/analysis-process.md)

# Citations

- SYSMOD – The Systems Modeling Toolbox, 3rd edition. Tim Weilkiens, MBSE4U, 2020. Section 4.9.

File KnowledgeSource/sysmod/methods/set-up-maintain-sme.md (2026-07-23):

---
type: SYSMOD Method
title: Set up and Maintain the SME
description: Configure the modeling tools and create a System Modeling Environment (SME) for the project or organization.
timestamp: 2026-07-01T00:00:00Z
---

Method 4.2 in SYSMOD. The core of the SME is a SysML modeling tool. This method covers the configuration and customization of the modeling tool and related toolchain to support the tailored MBSE Methodology.

# Purpose

Provide a suitable SME to perform the tailored MBSE Methodology.

# Description

Out-of-the-box, a SysML modeling tool provides the whole set of SysML model elements and some extensions defined by the tool vendor. It is necessary to enable methodology-specific extensions to use a SysML modeling tool for a tailored MBSE Methodology.

Additionally, you should remove superfluous model elements from the toolbox and add convenience functions for a better user experience. If required, model libraries must be made accessible, and toolchains to other tools (requirements management, simulation) must be established.

Besides the SysML tool, other tools are typically part of the SME. They must also be customized.

# Relationships

**Primary Performer:** [SME Administrator](../roles/sme-administrator.md)

**Inputs:**
- [5.1 MBSE Methodology](../products/mbse-methodology.md)

**Outputs:**
- [5.2 System Modeling Environment (SME)](../products/system-modeling-environment.md)

**ISO 15288 Process:** Infrastructure Management

**Guidance:**
- [7.1 How to Set up an Initial Package Structure](../guidances/setup-package-structure.md)

**Part of Process:**
- [SYSMOD Infrastructure Process](../processes/infrastructure-process.md)

# Citations

- SYSMOD – The Systems Modeling Toolbox, 3rd edition. Tim Weilkiens, MBSE4U, 2020. Section 4.2.

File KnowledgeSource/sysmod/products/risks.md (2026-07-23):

---
type: SYSMOD Product
title: Risks
description: The Risks product specifies the potential inability to achieve the System Objectives, linked to other model elements for traceability and integrated with or proxying an external risk management tool.
timestamp: 2026-07-01T00:00:00Z
---

Product 5.9 in SYSMOD. Requirements and architectures contain risks, and risks in turn have an impact on Requirements and architectures. It is essential to have the Risks and links to other elements in the model.

# Purpose

Requirements and architectures contain risks, and risks, in turn, have an impact on Requirements and architectures. It is essential to have the Risks and links to other elements in the model.

# Description

The Risks are linked to other model elements to ensure traceability and not to overlook the Risks. For lightweight risk management, the SYSMOD modeling of the Risks could be sufficient. If the Risks are managed in an external risk management tool, the Risks in the model are proxies to establish links and traceability to other model elements.

# Relationships

**Responsibility:** [Requirements Engineer](../roles/requirements-engineer.md)

**Output of Methods:**
- [4.9 Model Risks](../methods/model-risks.md)

**Input of Methods:**
- [4.10 Model Requirements](../methods/model-requirements.md)

**Representation:**
- SysML requirements diagrams, tables, and matrices
- SYSMOD stereotype «risk»

**Related Guidance:** [7.7 How to Model Risks](../guidances/model-risks.md)

# Citations

- SYSMOD – The Systems Modeling Toolbox, 3rd edition. Tim Weilkiens, MBSE4U, 2020. Section 5.9.

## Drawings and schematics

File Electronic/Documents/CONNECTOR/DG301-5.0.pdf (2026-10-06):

P

# roduct

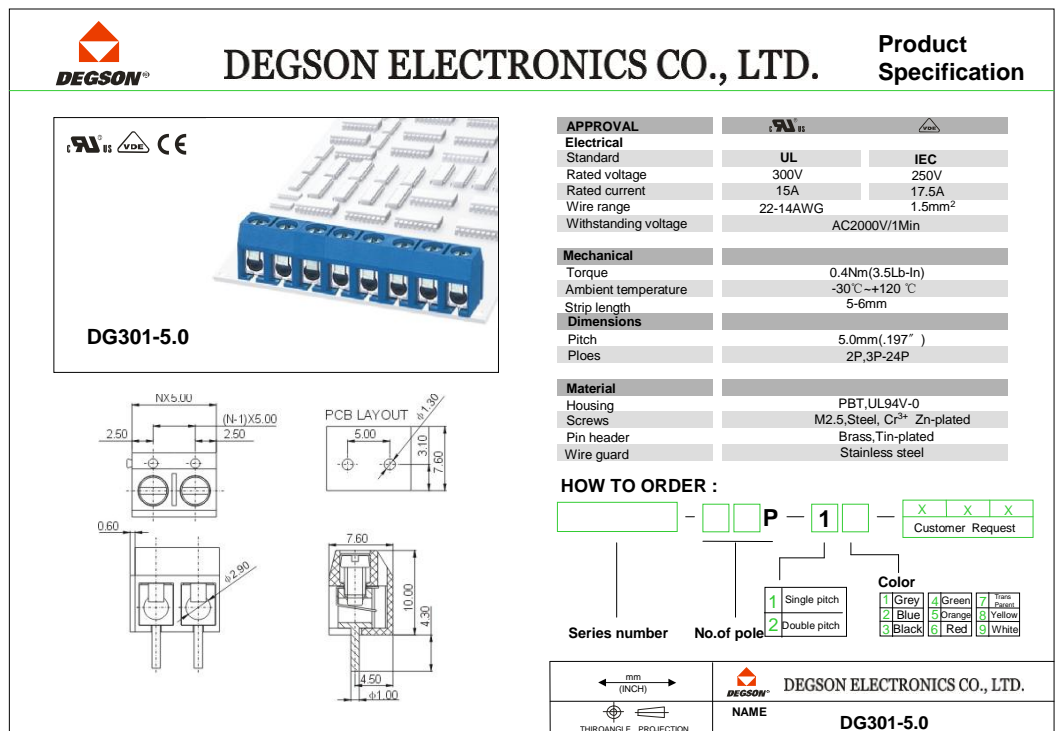
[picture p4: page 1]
AME; (INCH); pec; tion; HIR; GLE; TION; APP; VAL; lec; ical; tandard Ra; ted; oltage; urr; ent; Wir; range; Wit; tandin; olt; age; Mec; cal; bie; mpe; ure; rip len; gth; ime; sions; Pitch Ploes Mater; ial; Hou; sing; Scr; ews Pin header; ainless; teel; el, Cr³⁺; pla; Min; AWG; IEC; rque; e guard; ass,Tin; TO ORD; ber; Sin; gle; pitch; Grey; oubl; f pole; Blue Black; lor; reen; range Red; ellow White; equ; est

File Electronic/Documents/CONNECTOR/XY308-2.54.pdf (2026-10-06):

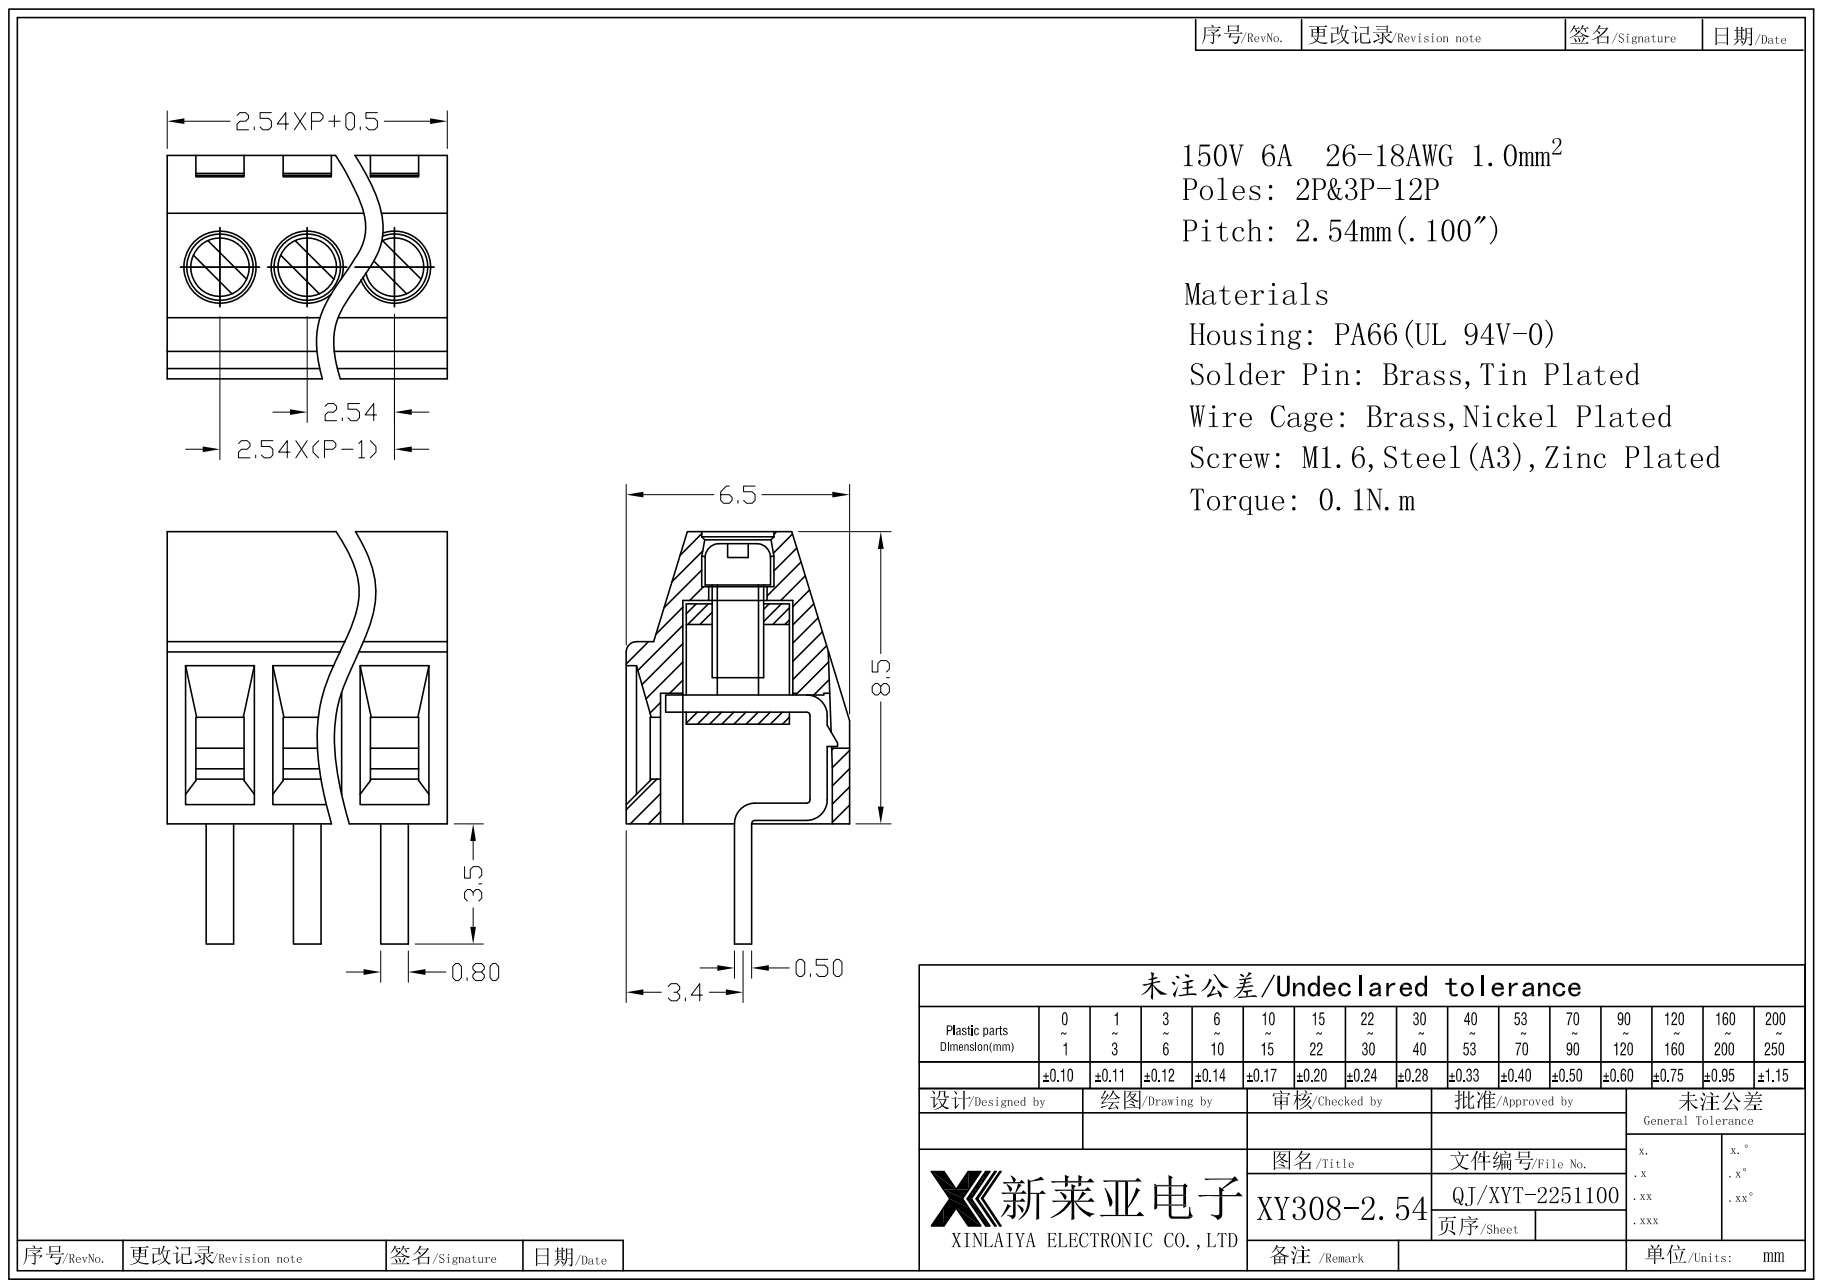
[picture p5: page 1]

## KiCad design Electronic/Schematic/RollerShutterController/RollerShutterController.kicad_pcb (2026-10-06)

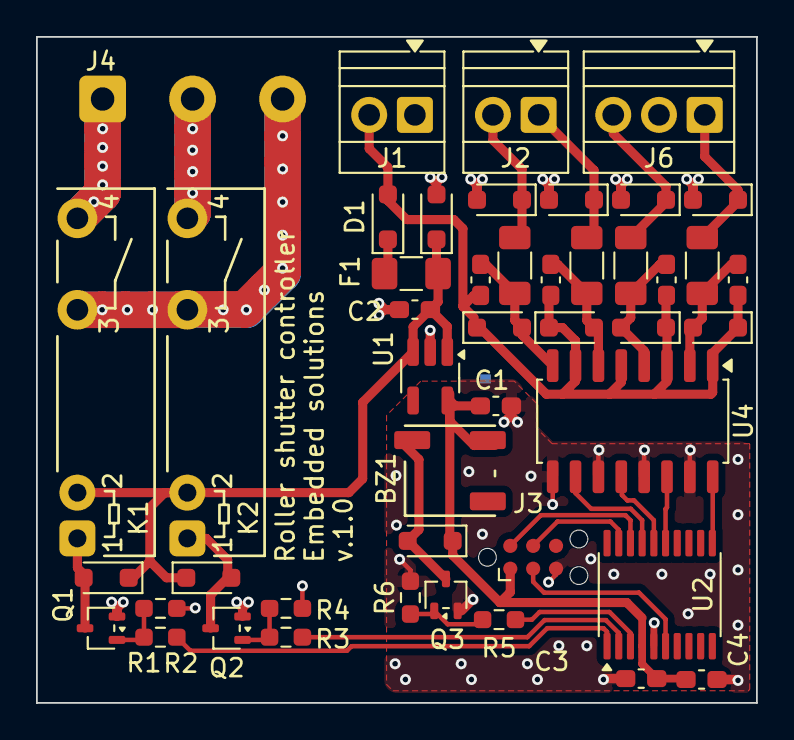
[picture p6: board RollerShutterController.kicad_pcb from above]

Board: 2 copper layers, 40.0 x 37.0 mm, 47 parts (1 on the bottom side), 33 nets.

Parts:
BZ1: Buzzer; LD-BZEL-T56-0505
C1, C2, C4: 1u 25V; C_0603_1608Metric_Pad1.08x0.95mm_HandSolder
C3, C5, C6, C7, C8: 100n 50V; C_0603_1608Metric_Pad1.08x0.95mm_HandSolder
D1: SDB160WS-AQ; D_SOD-323_HandSoldering
D2, D6, D7, D8, D9: STS321150U751; D_SOD-323_HandSoldering
D3, D4, D5, D12, D13, D14, D15: 1N4148WSTR; D_SOD-323_HandSoldering
F1: SN005-60; Fuse_1206_3216Metric_Pad1.42x1.75mm_HandSolder
J1, J2: Conn_01x02_Socket; TerminalBlock_Xinya_XY308-2.54-2P_1x02_P2.54mm_Horizontal
J3: TC2030; Tag-Connect_TC2030-IDC-NL_2x03_P1.27mm_Vertical
J4: Conn_01x03_Socket; DG301-5.0
J6: Conn_01x03_Socket; TerminalBlock_Xinya_XY308-2.54-3P_1x03_P2.54mm_Horizontal
JP1: SolderJumper_2_Bridged; SolderJumper-2_P1.3mm_Bridged_Pad1.0x1.5mm
K1, K2: AZ921-1A-12DE; AZ921
Q1, Q2, Q3: BSS138; SOT-323_SC-70
R1, R4, R6: 100k; R_0603_1608Metric_Pad0.98x0.95mm_HandSolder
R2, R3, R5: 330R; R_0603_1608Metric_Pad0.98x0.95mm_HandSolder
R8, R9, R11, R13: 1K; R_1206_3216Metric_Pad1.30x1.75mm_HandSolder
U1: LDK320M33R; SOT-23-5_HandSoldering
U2: STM32C011F4Px; TSSOP-20_4.4x6.5mm_P0.65mm
U4: LTV-247; SOP-16_4.4x10.4mm_P1.27mm

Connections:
230V_AC: J4.3, K1.13, K2.13
+3V3: BZ1.1 (+), C1.1, C3.1, C4.1, D5.1 (K), J3.1, U1.5 (OUT), U2.4 (VDD)
+12V: C5.1, C6.1, C7.1, C8.1, D1.2 (A), D12.1 (K), D13.1 (K), D14.1 (K), D15.1 (K), J1.2, U4.1, U4.3, U4.5, U4.7
+12V_SAFE: C2.1, D2.1 (K), D3.1 (K), D4.1 (K), F1.2, K1.A2, K2.A2, U1.1 (IN), U1.3 (EN)
BUTTON_LOCAL_DOWN: U2.11 (PA4), U4.16
BUTTON_LOCAL_DOWN_EXT: D9.1 (K), J6.1, R13.1
BUTTON_LOCAL_UP: U2.15 (PA8), U4.14
BUTTON_LOCAL_UP_EXT: D8.1 (K), J6.3, R11.1
BUTTON_REMOTE_DOWN: U2.16 (PA9/PA11), U4.12
BUTTON_REMOTE_DOWN_EXT: D7.1 (K), J2.1, R9.1
BUTTON_REMOTE_UP: U2.17 (PA10/PA12), U4.10
BUTTON_REMOTE_UP_EXT: D6.1 (K), J2.2, R8.1
BUZZER: R5.1, U2.3 (PC15)
GND: C1.2, C3.2, C4.2, J3.5, JP1.2 (B), Q3.2 (S), R6.2, U2.5 (VSS), U4.9, U4.11, U4.13, U4.15
GNDPWR: C2.2, D2.2 (A), D6.2 (A), D7.2 (A), D8.2 (A), D9.2 (A), J1.1, J6.2, JP1.1 (A), Q1.2 (S), Q2.2 (S), R1.2, R4.2, U1.2 (GND)
MOTOR_DOWN: J4.2, K2.14
MOTOR_UP: J4.1, K1.14
NRST: J3.3, U2.6 (PF2)
unnamed: BZ1.2 (-), D5.2 (A), Q3.3 (D)
unnamed: D1.1 (K), F1.1
unnamed: D3.2 (A), K1.A1, Q1.3 (D)
unnamed: D4.2 (A), K2.A1, Q2.3 (D)
unnamed: C5.2, D12.2 (A), R8.2, U4.8
unnamed: C6.2, D13.2 (A), R9.2, U4.6
unnamed: C7.2, D14.2 (A), R11.2, U4.4
unnamed: C8.2, D15.2 (A), R13.2, U4.2
unnamed: Q1.1 (G), R1.1, R2.2
unnamed: Q2.1 (G), R3.2, R4.1
unnamed: Q3.1 (G), R5.2, R6.1
RELAY_DOWN: R3.1, U2.2 (PC14)
RELAY_UP: R2.1, U2.1 (PB7)
SWCLK: J3.4, U2.19 (PA14)
SWDIO: J3.2, U2.18 (PA13)

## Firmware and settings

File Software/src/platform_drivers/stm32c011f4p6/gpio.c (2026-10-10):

/*
 * gpio.c
 *
 * STM32C011F4P6 GPIO driver
 */

/* Includes ------------------------------------------------------------------*/
#include "gpio.h"

#include <stdbool.h>
#include <stddef.h>
#include <string.h>

#include "gpio_pins.h"
#include "stm32c0xx_ll_bus.h"
#include "stm32c0xx_ll_exti.h"
#include "stm32c0xx_ll_gpio.h"
#include "stm32c0xx_ll_system.h"

/* Private defines -----------------------------------------------------------*/

#define MAX_NUMBER_OF_SUPPORTED_PINS (10U)

/* Private types ------------------------------------------------------------*/

enum interrupt_pin_polarity
{
    INTERRUPT_PIN_POLARITY_HITOLO,
    INTERRUPT_PIN_POLARITY_LOTOHI,
    INTERRUPT_PIN_POLARITY_TOGGLE
};

enum interrupt_state
{
    INTERRUPT_INACTIVE,
    INTERRUPT_ACTIVE
};

struct exti_configuration
{
    uint32_t IRQ;
    uint32_t exti_line;
    uint32_t exti_config_line;
    uint32_t exti_config_port;
};

struct pin_context
{
    const struct gpio_pin *info;

    struct exti_configuration exti;

    void (*callback)(void *);
    void *callback_data;

    bool is_used;
};

/* Private variables --------------------------------------------------------*/

static bool is_initialized = false;

static struct pin_context pin_context_list[MAX_NUMBER_OF_SUPPORTED_PINS];

/* Private functions --------------------------------------------------------*/

static enum interrupt_pin_polarity interrupt_pin_polarity_from_activity(enum board_input_polarity polarity,
                                                                        enum interrupt_pin_activity activity)
{
    if (activity)
    {
        return (polarity == ACTIVE_HIGH) ? INTERRUPT_PIN_POLARITY_LOTOHI : INTERRUPT_PIN_POLARITY_HITOLO;
    }
    else
    {
        return (polarity != ACTIVE_HIGH) ? INTERRUPT_PIN_POLARITY_LOTOHI : INTERRUPT_PIN_POLARITY_HITOLO;
    }
}

/*
 * Find context associated with an EXTI line and execute its callback.
 */
static void find_context_and_call_callback(uint32_t exti_line)
{
    for (uint32_t pin = 0U; pin < MAX_NUMBER_OF_SUPPORTED_PINS; pin++)
    {
        if (pin_context_list[pin].is_used && pin_context_list[pin].exti.exti_line == exti_line)
        {
            if (pin_context_list[pin].callback != NULL)
            {
                pin_context_list[pin].callback(pin_context_list[pin].callback_data);
            }

            break;
        }
    }
}

/*
 * STM32C0 EXTI has separate rising and falling pending flags.
 */
static uint32_t get_pending_interrupt_lines(void)
{
    uint32_t rising_flags = LL_EXTI_ReadRisingFlag_0_31(LL_EXTI_LINE_ALL_0_31);

    uint32_t falling_flags = LL_EXTI_ReadFallingFlag_0_31(LL_EXTI_LINE_ALL_0_31);

    return rising_flags | falling_flags;
}

static void irq_handler(void)
{
    uint32_t pending;

    while ((pending = get_pending_interrupt_lines()) != 0U)
    {
        uint32_t active_exti_line = (uint32_t)(1UL << __builtin_ctz(pending));

        /*
         * STM32C0 has separate rising/falling pending registers.
         * Clear both to handle both possible trigger sources.
         */
        LL_EXTI_ClearRisingFlag_0_31(active_exti_line);
        LL_EXTI_ClearFallingFlag_0_31(active_exti_line);

        find_context_and_call_callback(active_exti_line);
    }
}

/* IRQ handlers -------------------------------------------------------------*/

/**
 * @brief  This function handles external line 0_1 interrupt request.
 */
void EXTI0_1_IRQHandler(void)
{
    irq_handler();
}

/**
 * @brief  This function handles external line 2_3 interrupt request.
 */
void EXTI2_3_IRQHandler(void)
{
    irq_handler();
}

/**
 * @brief  This function handles external line 4_15 interrupt request.
 */
void EXTI4_15_IRQHandler(void)
{
    irq_handler();
}

/* Pin context management ---------------------------------------------------*/

static struct pin_context *find_free_entry_for_pin(void)
{
    for (uint8_t handle_idx = 0U; handle_idx < MAX_NUMBER_OF_SUPPORTED_PINS; handle_idx++)
    {
        if (!pin_context_list[handle_idx].is_used)
        {
            return &pin_context_list[handle_idx];
        }
    }

    return NULL;
}

static struct pin_context *entry_add(const struct gpio_pin *info)
{
    struct pin_context *handle = find_free_entry_for_pin();

    if (handle != NULL)
    {
        handle->info = info;
        handle->callback = NULL;
        handle->callback_data = NULL;
        handle->is_used = true;

        return handle;
    }

    return NULL;
}
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

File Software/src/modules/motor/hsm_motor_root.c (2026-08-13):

/*
 * blink.c
 *
 *  Created on: 1 Oct 2022
 *      Author: Kamil Lazowski
 */

/* Private includes ----------------------------------------------------------*/

#include "gpio.h"
#include "gpio_pins.h"

#include "em_event.h"
#include "em_timer.h"
#include "executors.h"

#include "em_event.h"
#include "hsm.h"

#include "hsm_motor.h"
#include "hsm_motor_internal.h"
#include "hsm_motor_states.h"

#include "configuration.h"
#include "motor_configuration.h"

#include "utils.h"

/* Private define ------------------------------------------------------------*/

/* Private typedef -----------------------------------------------------------*/
/* Private macro -------------------------------------------------------------*/
/* Private variables ---------------------------------------------------------*/
struct hsm_motor_context motor = {0};

/* Private function prototypes -----------------------------------------------*/
/* Private function bodies ---------------------------------------------------*/
static void init_motor_hsm(struct hsm_motor_context *hsm)
{
    const state_t *initial_state;
    initial_state = hsm_motor_idle;
    hsm->machine.State = initial_state;
    traverse_state(&hsm->machine, initial_state);
}

static void create_safety_timer(struct em_timer *timer, void *context, uint32_t timeout)
{
    /* Debounce timer. */
    em_timer_create(timer, NULL, false, context);
    em_timer_set_event_id(timer, SAFETY_TIMER_EVENT_ID);
    em_timer_set_period(timer, timeout);
}

static void configure_gpio(struct motor *motor, const enum board_input_pin_id motor_pin_id)
{
    motor->gpio_info = find_gpio_pin_context(motor_pin_id);
    gpio_pin_init(motor->gpio_info, &motor->gpio_handle);
    gpio_output_configure(motor->gpio_handle, motor->gpio_info->mode);
    gpio_output_clear(motor->gpio_handle);
}

static void configure_motors(struct hsm_motor_context *hsm, const struct motor_configuration *config)
{
    configure_gpio(&hsm->motor_up, config->motor_up_pin_id);
    configure_gpio(&hsm->motor_down, config->motor_down_pin_id);
    create_safety_timer(&hsm->safety_timer, hsm, config->timeout);
}

/* Private function bodies ---------------------------------------------------*/

static void handle_init_event(uint32_t flags)
{
    (void)(flags);
    struct hsm_motor_context *hsm = &motor;
    uint8_t devices_count = 0;
    const struct device_configuration *list = get_list_of_devices_by_type(DEVICE_TYPE_MOTOR, &devices_count);

    if ((list != NULL) && (devices_count == 1))
    {
        const struct device_configuration *current_device = (const struct device_configuration *)list;
        configure_motors(hsm, (const struct motor_configuration *)current_device->config);
        init_motor_hsm(hsm);
    }
}

static void handle_test_event(void *event)
{
    (void)(event);
    motor.machine.Event = event;
    state_machine_t *const machineList[] = {&motor.machine};
    dispatch_event(machineList, 1);
}

static state_machine_result_t event_handler(state_machine_t *const pmachine)
{
    (void)(pmachine);

    return EVENT_UN_HANDLED;
}

const struct subscriber motor_subscriber = {.init = handle_init_event, .handle_event = handle_test_event};
CREATE_LIST_OF_SUBSCRIBERS_IN_EXECUTOR(main_executor_subscribers, main_executor, ADD_SUBSCRIBER(&motor_subscriber))
CREATE_EVENT(SAFETY_TIMER_EVENT, ADD_SUBSCRIBER(&main_executor_subscribers))

const state_t hsm_motor_root[] = {
    {event_handler, NULL, NULL, NULL, NULL, 0},
};

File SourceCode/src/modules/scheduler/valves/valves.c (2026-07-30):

/*
 * valves.c
 *
 *  Created on: 14 Mar 2023
 *      Author: dev
 */
#include <stddef.h>

#include "gpio.h"
#include "valves.h"

#define MAX_NUMBER_OF_SUPPORTED_VALVES (4)

struct valve_context
{
    const struct gpio_pin *info;
    void *pin_handle;
    bool is_opened;
    bool is_used;
};

static struct valve_context valve_context_list[MAX_NUMBER_OF_SUPPORTED_VALVES];

static struct valve_context *find_free_entry_for_pin(void)
{
    for (uint8_t handle_idx = 0; handle_idx < MAX_NUMBER_OF_SUPPORTED_VALVES; handle_idx++)
    {
        if (!valve_context_list[handle_idx].is_used)
        {
            return &valve_context_list[handle_idx];
        }
    }
    return NULL;
}

static struct valve_context *entry_add(const struct gpio_pin *info)
{
    struct valve_context *handle = find_free_entry_for_pin();
    if (handle != NULL)
    {
        handle->info = info;
        handle->is_used = true;
        return handle;
    }
    return NULL;
}

static struct valve_context *find_matching_entry_for_info(const struct gpio_pin *info)
{
    for (uint8_t handle_idx = 0; handle_idx < MAX_NUMBER_OF_SUPPORTED_VALVES; handle_idx++)
    {
        if (info == valve_context_list[handle_idx].info)
        {
            return &valve_context_list[handle_idx];
        }
    }
    return NULL;
}

static enum valve_status find_or_create_pin_entry_if_not_existing(const struct gpio_pin *info, void **handle)
{
    struct valve_context *entry = find_matching_entry_for_info(info);
    if (entry == NULL)
    {
        entry = entry_add(info);
        if (entry == NULL)
        {
            *handle = NULL;
            return VALVE_NO_MEMORY;
        }
    }
    *handle = (void *)entry;
    return VALVE_OK;
}

void valve_initialize(const void *valve_info, void **valve_handle)
{
    find_or_create_pin_entry_if_not_existing(valve_info, valve_handle);
    if (*valve_handle)
    {
        struct valve_context *handle = *valve_handle;
        gpio_pin_init(valve_info, &handle->pin_handle);
    }
}

void valve_open(void *valve_handle)
{
    struct valve_context *handle = valve_handle;
    gpio_output_set(handle->pin_handle);
    handle->is_opened = true;
}

void valve_close(void *valve_handle)
{
    struct valve_context *handle = valve_handle;
    gpio_output_clear(handle->pin_handle);
    handle->is_opened = false;
}

bool valve_is_open(void *valve_handle)
{
    struct valve_context *handle = valve_handle;
    return handle->is_opened;
}

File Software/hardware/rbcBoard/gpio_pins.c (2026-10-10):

/*
 * gpio_pins.c
 *
 *  Created on: 9 Mar 2023
 *      Author: dev
 */
#include <stddef.h>

#include "gpio_pins.h"
#include "stm32c0xx_ll_gpio.h"


/* User button */
#define BUTTON_LOCAL_UP_PIN_PIN   LL_GPIO_PIN_8
#define BUTTON_LOCAL_UP_PIN_PORT ((uint32_t)GPIOA)

#define BUTTON_LOCAL_DOWN_PIN_PIN      (LL_GPIO_PIN_4)
#define BUTTON_LOCAL_DOWN_PIN_PORT     ((uint32_t)GPIOA)

#define BUTTON_REMOTE_UP_PIN_PIN      (LL_GPIO_PIN_12)
#define BUTTON_REMOTE_UP_PIN_PORT     ((uint32_t)GPIOA)

#define BUTTON_REMOTE_DOWN_PIN_PIN      (LL_GPIO_PIN_11)
#define BUTTON_REMOTE_DOWN_PIN_PORT     ((uint32_t)GPIOA)

#define MOTOR_UP_PIN_PIN      (LL_GPIO_PIN_7)
#define MOTOR_UP_PIN_PORT     ((uint32_t)GPIOB)

#define MOTOR_DOWN_PIN_PIN      (LL_GPIO_PIN_14)
#define MOTOR_DOWN_PIN_PORT     ((uint32_t)GPIOC)

/* LED port */
#define BUZZER_PIN_PIN      (LL_GPIO_PIN_15)
#define BUZZER_PIN_PORT     ((uint32_t)GPIOC)

const struct gpio_pin gpio_pins[] = {
    { BUTTON_LOCAL_UP_PIN_ID, BUTTON_LOCAL_UP_PIN_PIN, BUTTON_LOCAL_UP_PIN_PORT, ACTIVE_LOW, PIN_PULLUP, PIN_MODE_INPUT, PIN_SPEED_LOW, 0, BOTH_EDGES_INTERRUPTS },
    { BUTTON_LOCAL_DOWN_PIN_ID, BUTTON_LOCAL_DOWN_PIN_PIN, BUTTON_LOCAL_DOWN_PIN_PORT, ACTIVE_LOW, PIN_PULLUP, PIN_MODE_INPUT, PIN_SPEED_LOW, 0, BOTH_EDGES_INTERRUPTS },
    { BUTTON_REMOTE_UP_PIN_ID, BUTTON_REMOTE_UP_PIN_PIN, BUTTON_REMOTE_UP_PIN_PORT, ACTIVE_LOW, PIN_PULLUP, PIN_MODE_INPUT, PIN_SPEED_LOW, 0, BOTH_EDGES_INTERRUPTS },
    { BUTTON_REMOTE_DOWN_PIN_ID, BUTTON_REMOTE_DOWN_PIN_PIN, BUTTON_REMOTE_DOWN_PIN_PORT, ACTIVE_LOW, PIN_PULLUP, PIN_MODE_INPUT, PIN_SPEED_LOW, 0, BOTH_EDGES_INTERRUPTS },
    { MOTOR_UP_PIN_ID, MOTOR_UP_PIN_PIN, MOTOR_UP_PIN_PORT, ACTIVE_HIGH, PIN_PULLDOWN, PIN_MODE_OUTPUT_PUSH_PULL, PIN_SPEED_LOW,0, BOTH_EDGES_INTERRUPTS },
    { MOTOR_DOWN_PIN_ID, MOTOR_DOWN_PIN_PIN, MOTOR_DOWN_PIN_PORT, ACTIVE_HIGH, PIN_PULLDOWN, PIN_MODE_OUTPUT_PUSH_PULL, PIN_SPEED_LOW,0, BOTH_EDGES_INTERRUPTS },
    { BUZZER_PIN_ID, BUZZER_PIN_PIN, BUZZER_PIN_PORT, ACTIVE_HIGH, PIN_NO_PULL, PIN_MODE_ALTERNATE, PIN_SPEED_LOW, LL_GPIO_AF_3, BOTH_EDGES_INTERRUPTS },
};

const uint8_t gpio_pins_size = sizeof(gpio_pins) / sizeof(gpio_pins[0]);

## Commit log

2026-06-18 Added Use Case Activities, but haven't linked them.
2026-06-19 Added tracebility from use cases to use case activities.
2026-06-23 Corrected use-case activities and started work on functional architecture.
2026-06-24 Refactored use-cases and use case activities. Tracebilty not fixed.
2026-06-24 Fixed tracebility.
2026-08-04 Fixed failing test due to API change.
    [gpio_mock.c, gpio_pins.c]
2026-08-04 Preparation for first button tests.
2026-08-05 Extracted configuration to separate source.
    [configuration.h]
2026-08-05 Started adding tests for buttons.
    [configuration_mock.h]
2026-08-06 Added test for short button press scenario.
2026-08-09 Added tests for button state machine.
2026-08-10 Formatted files.
    [configuration.h, configuration_mock.h]
2026-08-10 Suiting for nucleo-board test.
2026-08-10 Succesfullt tested buttons on nucleo F091
2026-08-11 Added motor implementation, but not tested.
    [configuration.h]
2026-08-11 Started adding tests for motor.
2026-08-12 Added motor tests.
2026-08-13 Added buzzer hsm.
    [configuration.h]
2026-08-19 Added first test for controller auto mode.
    [configuration.h]
2026-08-26 Formatted code.
    [configuration.h]
2026-09-04 Started work on schematic.
    [Elements list.ods, RollerShutterController.kicad_pcb, RollerShutterController.kicad_sch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]
2026-10-06 Added electronic project.
    [Elements list.ods, RollerShutterController.csv, RollerShutterController.kicad_pcb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]
2026-10-07 Added stm32C0 target for software.
    [configuration.h, configuration_mock.h]
2026-10-10 Buzzer driver works correctly.
    [configuration.c, gpio.c, gpio_pins.c]
2026-10-14 Added PCB production files.
2026-10-16 Added IWDG driver.
